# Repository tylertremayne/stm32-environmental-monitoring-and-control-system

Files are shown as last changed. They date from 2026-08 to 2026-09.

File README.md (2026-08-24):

# STM32 Environmental Monitoring and Control System

#### An embedded environmental monitoring and fan control system built around the STM32F401RE.

## Planned Features
- Temperature sensing
- Ambient light sensing
- OLED display
- PWM-controlled DC fan
- UART telemetry
- Timer-driven sensor sampling
- Automatic and manual control modes

## Hardware
- STM32 Nucleo-F401RE

## Status
-- Project setup

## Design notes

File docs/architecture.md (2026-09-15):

# Test Results

## ADC Potentiometer Test
- Input pin: PA0 / A0
- ADC peripheral: ADC1
- Expected range: 0–4095
- Observed minimum:
- Observed midpoint:
- Observed maximum:
- Notes:

## Temperature Sensor Test
- Sensor:
- Input pin: PA1 / A1
- Expected room-temperature voltage:
- Observed raw ADC value:
- Calculated voltage:
- Calculated temperature:
- Notes:

## UART Test
- Peripheral: USART2
- Baud rate: 115200
- Data format: 8-N-1
- Terminal: PuTTY
- Result:
- Notes:

## Fan Control Test
- Control pin: PA4 / A2
- MOSFET module:
- Fan supply:
- Fan ON test:
- Fan OFF test:
- Automatic control test:
- Notes:

## Full System Test
- Test duration:
- Temperature response:
- Setpoint response:
- Fan response:
- Stability issues:
- Final result:

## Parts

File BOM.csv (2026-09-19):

Component | Part Number | Quantity | Purpose | Power/Voltage | Status
- STM32 Nucleo | NUCLEO-F401RE | 1 | Main microcontroller | USB/3.3V | Installed
- Potentiometer | TBD | 1 | User temperature setpoint | 3.3V | Installed
- Temperature Sensor | TMP36GZ | 1 | Ambient temperature sensing | 3.3V | Installed
- MOSFET Module | MTDELE 5V-36V 15A PWM Module | 1 | Fan switching/control | 5V load side | Installed
- Cooling Fan | 3007 30x30x7mm Brushless Fan | 1 | Cooling load | 5V | Installed
- OLED Display | SSD1306 0.96in I2C 128x64 | 1 | Local system display | 3.3V logic | Ordered/Planned
- External Power Supply | 5V 3A regulated supply | 1 | Fan/MOSFET power | 5V | Ordered
- Breadboard | TBD | 1 | Prototype construction | N/A | Installed
- Jumper Wires | TBD | Multiple | Electrical connections | N/A | Installed
- Male Header Pins | 0.1in pitch | 1 set | MOSFET control header | N/A | Needs soldering

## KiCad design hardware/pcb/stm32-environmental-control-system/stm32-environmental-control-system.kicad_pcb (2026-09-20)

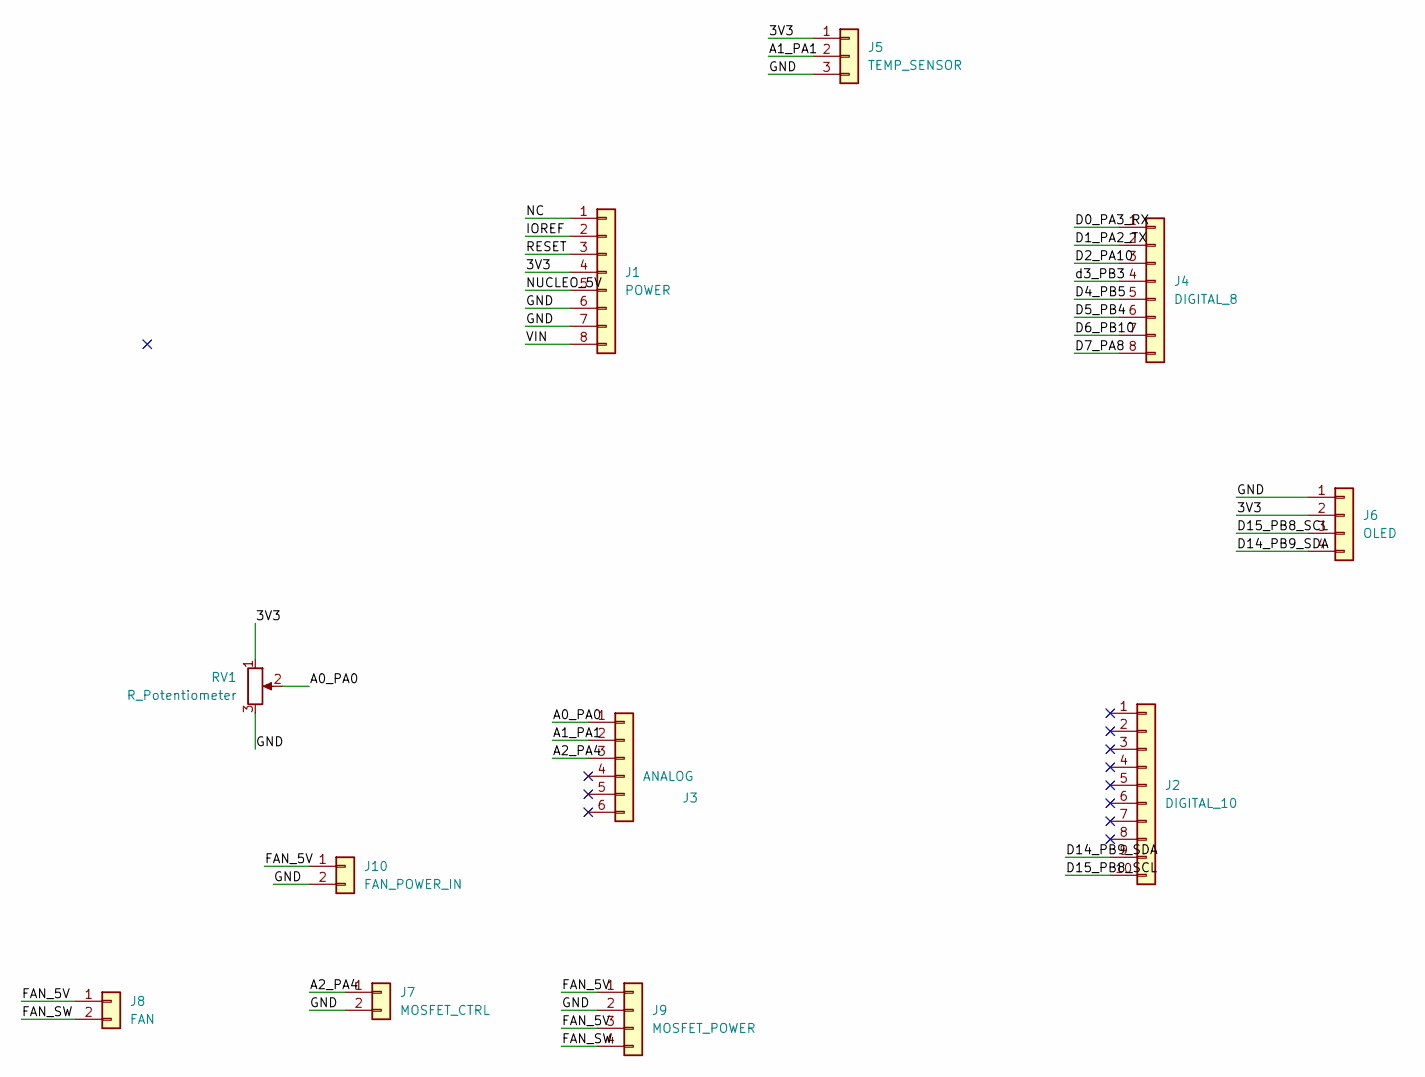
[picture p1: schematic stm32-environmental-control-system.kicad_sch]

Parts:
J1: POWER; PinHeader_1x08_P2.54mm_Vertical
J2: DIGITAL_10; PinHeader_1x10_P2.54mm_Vertical
J3: ANALOG; PinHeader_1x06_P2.54mm_Vertical
J4: DIGITAL_8; PinHeader_1x08_P2.54mm_Vertical
J5: TEMP_SENSOR; FanPinHeader_1x03_P2.54mm_Vertical
J6: OLED; FanPinHeader_1x04_P2.54mm_Vertical
J7: MOSFET_CTRL; PinHeader_1x02_P2.54mm_Vertical
J8: FAN; PinHeader_1x02_P2.54mm_Vertical
J9: MOSFET_POWER; FanPinHeader_1x04_P2.54mm_Vertical
J10: FAN_POWER_IN; PinHeader_1x02_P2.54mm_Vertical
RV1: R_Potentiometer; PinHeader_1x03_P2.54mm_Vertical

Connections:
/3V3: J1.4, J5.1, J6.2, RV1.1
/A0_PA0: J3.1, RV1.2
/A1_PA1: J3.2, J5.2
/A2_PA4: J3.3, J7.1
/D0_PA3_RX: J4.1
/D1_PA2_TX: J4.2
/D2_PA10: J4.3
/D4_PB5: J4.5
/D5_PB4: J4.6
/D6_PB10: J4.7
/D7_PA8: J4.8
/D14_PB9_SDA: J2.9, J6.4
/D15_PB8_SCL: J2.10, J6.3
/FAN_5V: J8.1, J9.1, J9.3, J10.1
/FAN_SW: J8.2, J9.4
/GND: J1.6, J1.7, J5.3, J6.1, J7.2, J9.2, J10.2, RV1.3
/IOREF: J1.2
/NC: J1.1
/NUCLEO_5V: J1.5
/RESET: J1.3
/VIN: J1.8
/d3_PB3: J4.4

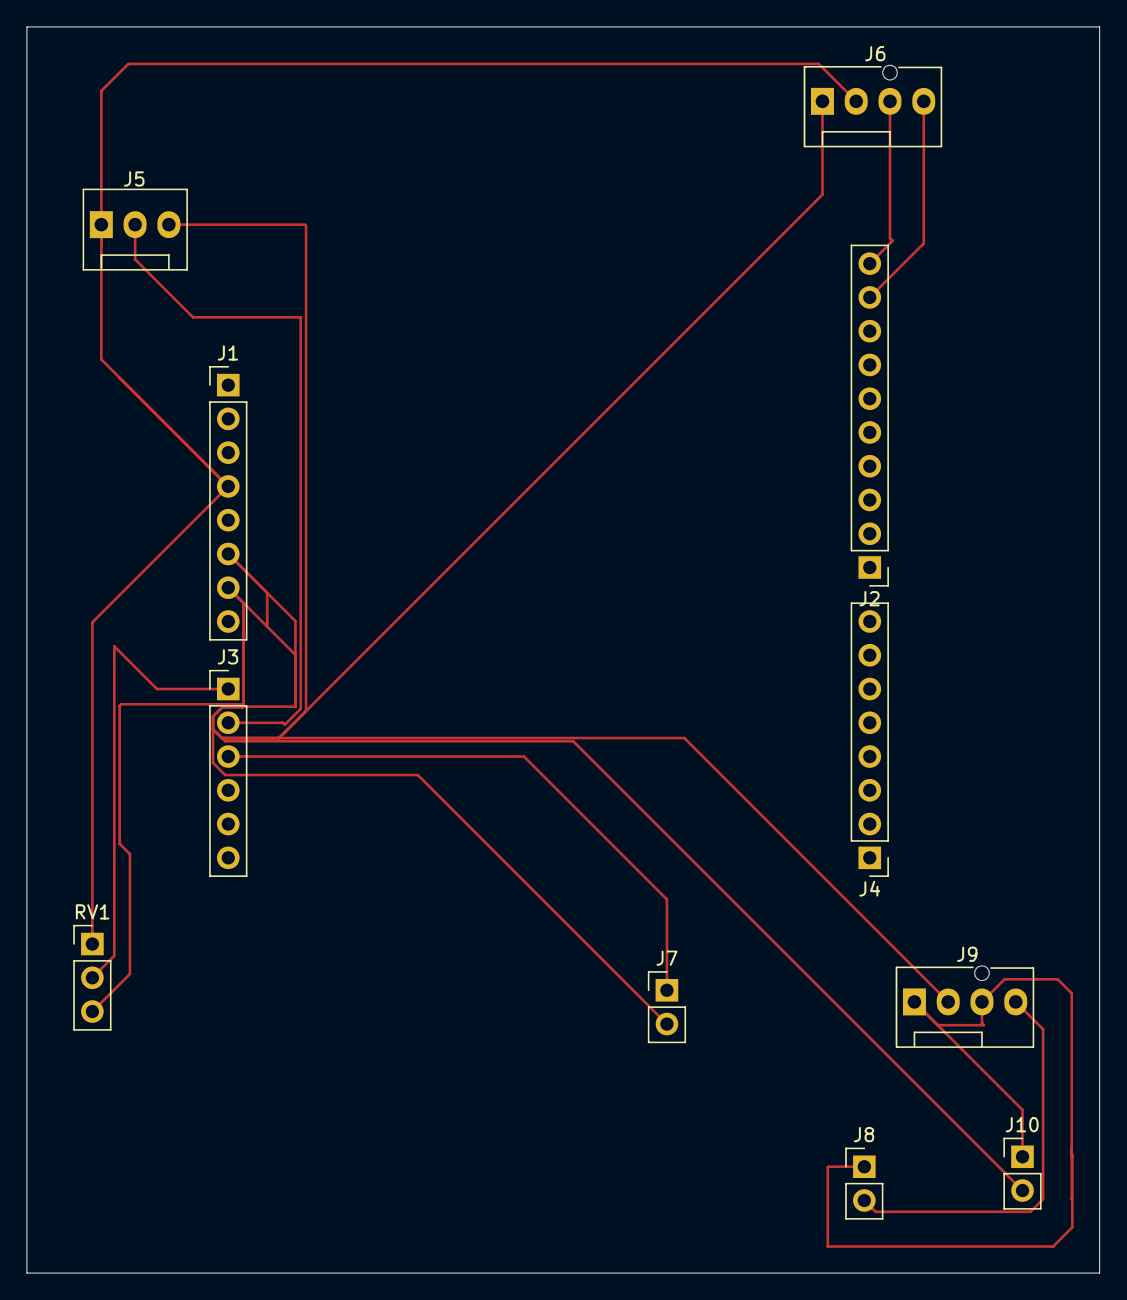
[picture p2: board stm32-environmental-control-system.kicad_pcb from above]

Board: 2 copper layers, 80.7 x 93.8 mm, 11 parts (0 on the bottom side), 9 nets.

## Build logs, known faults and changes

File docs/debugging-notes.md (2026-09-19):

# Debugging Notes

## STM32CubeIDE / CubeMX Setup
- Initial empty CubeIDE project did not include STM32 CMSIS device headers.
- Switched to STM32CubeMX to generate the project properly for the NUCLEO-F401RE.
- Generated project successfully built in STM32CubeIDE.

## UART Debugging
- USART2 configured for 115200 baud, 8-N-1.
- Used PuTTY through the ST-LINK Virtual COM Port.
- Encountered garbled output when terminal settings did not match the firmware configuration.
- Correcting the baud rate restored normal UART output.

## ADC Debugging
- Potentiometer connected to PA0 / A0 using ADC1_IN0.
- Initial two-channel ADC scan configuration caused the program to hang while waiting for the second conversion.
- Changed approach to manually configure and read ADC channels one at a time.
- PA0 used for potentiometer.
- PA1 used for temperature sensor.

## Temperature Sensor Debugging
- Original MCP9700AE produced unrealistic and unstable readings.
- Verified PA1 ADC path by tying A1 directly to ground; ADC correctly read near zero.
<<<<<<< HEAD
- Reconnecting the sensor caused abnormal readings again, confirming the issue was on the sensor side.
- Sensor was later overheated during orientation troubleshooting and is being replaced.
- Temporary solution to get a temperature in range was to offset calculated value by 20 degrees
=======
- New sensor is the TMP3600, reads 20 degrees below accurate temp. offset the read value by 20 degrees inside while(1)
>>>>>>> be844c1a9cfa12a298c5ffda54abaf0339f41847

## Fan / MOSFET Debugging
- MOSFET module arrived without the control header soldered.
- Temporary header-pin contact was used successfully for testing.
- PA4 / A2 configured as GPIO output for fan control.
- Fan successfully switched ON and OFF through the MOSFET module.
- Control header still needs to be permanently soldered.

## Current Known Issues
- Replacement temperature sensor still needs to be installed and verified.
- MOSFET control header needs permanent soldering.
- External 5 V supply still needs final integration.
- PWM fan-speed control and OLED display are not yet implemented.

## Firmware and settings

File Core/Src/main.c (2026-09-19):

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
/* Includes ------------------------------------------------------------------*/
#include "main.h"

/* USER CODE BEGIN Includes */
#include <stdio.h>
#include <string.h>
#include "ssd1306.h"
/* USER CODE END Includes */

ADC_HandleTypeDef hadc1;

I2C_HandleTypeDef hi2c1;

UART_HandleTypeDef huart2;

void SystemClock_Config(void);
static void MX_GPIO_Init(void);
static void MX_USART2_UART_Init(void);
static void MX_ADC1_Init(void);
static void MX_I2C1_Init(void);
/**
  * @brief  The application entry point.
  * @retval int
  */
int main(void)
{

  /* MCU Configuration--------------------------------------------------------*/

  /* Reset of all peripherals, Initializes the Flash interface and the Systick. */
  HAL_Init();

  /* Configure the system clock */
  SystemClock_Config();

  /* Initialize all configured peripherals */
  MX_GPIO_Init();
  MX_USART2_UART_Init();
  MX_ADC1_Init();
  MX_I2C1_Init();
  /* USER CODE BEGIN 2 */
  SSD1306_Init(&hi2c1);
  SSD1306_Clear();



  /* USER CODE END 2 */

  /* Infinite loop */
  /* USER CODE BEGIN WHILE */
  while (1)
  {
	  /* USER CODE BEGIN WHILE */
      uint32_t pot_raw;
      uint32_t temp_raw;
      uint32_t pot_sum = 0;
      uint32_t temp_sum = 0;

      float temp_voltage;
      float temperature_c;
      float setpoint_c;


      // rejects bad temp readings
      static float last_good_temp = 20.0f;
      float measured_temp;

      char msg[128];

      ADC_ChannelConfTypeDef sConfig = {0};
      /* =========================
         READ POTENTIOMETER - PA0
         ========================= */

      sConfig.Channel = ADC_CHANNEL_0;
      sConfig.Rank = 1;
      sConfig.SamplingTime = ADC_SAMPLETIME_84CYCLES;

      HAL_ADC_ConfigChannel(&hadc1, &sConfig);

      /* Throw away first conversion after switching channels */
      HAL_ADC_Start(&hadc1);
      HAL_ADC_PollForConversion(&hadc1, HAL_MAX_DELAY);
      HAL_ADC_GetValue(&hadc1);
      HAL_ADC_Stop(&hadc1);
      /* Average 8 real samples */
      pot_sum = 0;

      for (int i = 0; i < 8; i++)
      {
          HAL_ADC_Start(&hadc1);
          HAL_ADC_PollForConversion(&hadc1, HAL_MAX_DELAY);

          pot_sum += HAL_ADC_GetValue(&hadc1);

          HAL_ADC_Stop(&hadc1);
      }

      pot_raw = pot_sum / 8;

      /* Map potentiometer to 20 C - 60 C */
      setpoint_c =
          18.0f +
          ((float)pot_raw / 4095.0f) * 38.0f;

      /* =========================
         READ TMP36 - PA1
         ========================= */

      sConfig.Channel = ADC_CHANNEL_1;
      sConfig.Rank = 1;
      sConfig.SamplingTime = ADC_SAMPLETIME_84CYCLES;

      HAL_ADC_ConfigChannel(&hadc1, &sConfig);

      /* Throw away first conversion after switching channels */
      HAL_ADC_Start(&hadc1);
      HAL_ADC_PollForConversion(&hadc1, HAL_MAX_DELAY);
      HAL_ADC_GetValue(&hadc1);
      HAL_ADC_Stop(&hadc1);

      /* Average 16 temperature samples */
      temp_sum = 0;

      for (int i = 0; i < 16; i++)
      {
          HAL_ADC_Start(&hadc1);
          HAL_ADC_PollForConversion(&hadc1, HAL_MAX_DELAY);

          temp_sum += HAL_ADC_GetValue(&hadc1);

          HAL_ADC_Stop(&hadc1);
      }

      temp_raw = temp_sum / 16;

      /* =========================
         TEMPERATURE CALCULATION
         ========================= */

      temp_voltage =
          ((float)temp_raw / 4095.0f) * 3.3f;

      measured_temp =
          ((temp_voltage - 0.5f) / 0.01f) + 20.0f; //offset by 4 degrees

      /* Reject obviously bad readings */
      if (measured_temp >= 0.0f && measured_temp <= 60.0f)
      {
          last_good_temp = measured_temp;
      }

      temperature_c = last_good_temp;

      /* =========================
         FAN CONTROL
         ========================= */

		  if (temperature_c > setpoint_c)
		  {
			  HAL_GPIO_WritePin(
				  GPIOA,
				  GPIO_PIN_4,
				  GPIO_PIN_SET
			  );
		  }
		  else
		  {
			  HAL_GPIO_WritePin(
				  GPIOA,
				  GPIO_PIN_4,
				  GPIO_PIN_RESET
			  );
		  }

      /* =======================
       * OLED OUTPUT
       * =======================
       */

	  char temp_text[20];
	  char set_text[20];
	  char fan_text[20];

	  snprintf(temp_text, sizeof(temp_text),
			   "TEMP: %d C", (int)temperature_c);

	  snprintf(set_text, sizeof(set_text),
			   "SET: %d C", (int)setpoint_c);

	  snprintf(fan_text, sizeof(fan_text),
			   "FAN: %s",
			   (temperature_c > setpoint_c) ? "ON" : "OFF");

	  SSD1306_Clear();

	  SSD1306_WriteString(0, 4,  temp_text);
	  SSD1306_WriteString(0, 20, set_text);
	  SSD1306_WriteString(0, 36, fan_text);

	  SSD1306_UpdateScreen();



      HAL_UART_Transmit(
          &huart2,
          (uint8_t *)msg,
          strlen(msg),
          HAL_MAX_DELAY
      );

      /* =========================
         UART OUTPUT
         ========================= */

	  snprintf(
		  msg,
		  sizeof(msg),
		  "RAW: %lu | VOLT: %d mV | TEMP: %d C | SET: %d C | FAN: %s\r\n",
		  temp_raw,
		  (int)(temp_voltage * 1000.0f),
		  (int)temperature_c,
		  (int)setpoint_c,
		  (temperature_c > setpoint_c) ? "ON" : "OFF"
	  );


      HAL_Delay(500);

    /* USER CODE END WHILE */

    /* USER CODE BEGIN 3 */
  }
  /* USER CODE END 3 */
}

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


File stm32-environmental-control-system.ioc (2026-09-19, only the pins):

Mcu.UserName=STM32F401RETx
PA0-WKUP.Signal=ADCx_IN0
PA1.Signal=ADCx_IN1
PA13.GPIO_Label=TMS
PA13.Signal=SYS_JTMS-SWDIO
PA14.GPIO_Label=TCK
PA14.Signal=SYS_JTCK-SWCLK
PA2.GPIO_Label=USART_TX
PA2.Signal=USART2_TX
PA3.GPIO_Label=USART_RX
PA3.Signal=USART2_RX
PA4.Signal=GPIO_Output
PA5.GPIO_Label=LD2 [Green Led]
PA5.Signal=GPIO_Output
PB3.GPIO_Label=SWO
PB3.Signal=SYS_JTDO-SWO
PB8.Signal=I2C1_SCL
PB9.Signal=I2C1_SDA
PC13-ANTI_TAMP.GPIO_Label=B1 [Blue PushButton]
PC13-ANTI_TAMP.Signal=GPXTI13
PC14-OSC32_IN.Signal=RCC_OSC32_IN
PC15-OSC32_OUT.Signal=RCC_OSC32_OUT

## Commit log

2026-08-22 add initial stm32 project and LED blink
2026-08-22 add USART2 UART telemetry
2026-08-24 add ADC potentiometer input
2026-09-09 added MCP9700AE temp sensor
2026-09-14 add temp setpoint and fan control
2026-09-15 add project documentation structure
    [BOM.csv]
2026-09-17 debugged temp sensor & added dedicated external 5v power supply connected to mosfet
2026-09-20 complete pcb routing
    [stm32-environmental-control-system.kicad_pcb, stm32-environmental-control-system.kicad_sch]
2026-09-20 cretaed gerbers pcb ready to order
    [stm32-environmental-control-system-B_Cu.gbr, stm32-environmental-control-system-B_Mask.gbr, stm32-environmental-control-system-B_Paste.gbr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]
2026-09-20 add custom pcb design and manufactoring files

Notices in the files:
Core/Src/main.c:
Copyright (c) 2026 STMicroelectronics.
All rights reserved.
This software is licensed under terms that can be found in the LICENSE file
